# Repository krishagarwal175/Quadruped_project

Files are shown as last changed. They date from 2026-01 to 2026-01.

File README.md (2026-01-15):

# Quadruped Robot Project  
## Consolidated Technical & Progress Report

**Author:** Krish Agarwal  
**Project Duration:** June 2025 – January 2026  
**Status:** Active Development  
**Repository Purpose:** Complete technical, mechanical, electrical, and control-system documentation of the quadruped robot project.

---

## 1. Project Overview

This project documents the end-to-end design, development, and iterative refinement of a servo-actuated quadruped robot. Unlike gait-first hobby projects, this work follows a **stability-first, reflex-based control philosophy**, where standing balance, load management, and failure resilience are solved before aggressive locomotion.

The robot serves as:
- A **research testbed** for embedded control and legged stability
- A **hands-on systems engineering project** covering mechanics, electronics, and software
- A **foundation platform** for future ROS 2, perception, and learning-based extensions

---

## 2. Development Timeline Summary

### Phase 0–1: Concept & Pivot (Month 1)
- Initial work on a humanoid robot exposed critical power-to-weight limitations.
- A decisive pivot was made to a quadruped architecture.
- Learned Fusion 360, ROS, and Gazebo.
- Completed torque calculations and finalized a viable BOM.
- Began simulation-driven gait exploration.

**Key Outcome:** A mechanically and electrically feasible quadruped design.

---

### Phase 2: Mechanical Prototyping & Assembly (Month 2)
- All chassis and leg components 3D printed using PETG.
- Full mechanical assembly completed.
- Multiple redesigns to fix servo fitment, joint weakness, and infill-related failures.
- Hardware prototype became physically complete and software-ready.

**Key Outcome:** Fully assembled physical robot.

---

### Phase 3: Electrical & Platform Stabilization (Month 3)
- Introduced regulated high-current power delivery using a buck converter.
- Validated servo power distribution under load.
- Jetson Orin Nano OS corruption occurred during ROS setup → full system re-flash.
- Designed V2 leg parts after a structural failure.
- Established high-level control architecture plan.

**Key Outcome:** Stable electromechanical platform with lessons learned.

---

### Phase 4: Control Integration & Motion Refinement (Month 4)
- Full chassis rebuild to eliminate flex and rocking.
- Implemented smoother gait trajectories and reduced snap.
- Increased gait speed by ~1.3× after validation.
- Added balancing routines and removed brittle abort logic.
- Implemented configuration export and logging.
- Identified servo feedback and RL training as current hard limits.

**Key Outcome:** Stable, controllable robot with repeatable motion.

---

### Phase 5: Stability-First Control Architecture (Recent Month – Not in Prior Reports)
- Implemented **layered control architecture**:
  - Hardware abstraction
  - PD-based roll/pitch stabilization
  - Reflex behaviors and FSM-based limb control
- Developed brace reflexes and leg unloading detection.
- Enabled safe single-leg lift without collapse.
- Built real-time telemetry and manual override GUIs.
- Achieved controlled crawl-like motion under FSM supervision.

**Key Outcome:** Research-grade reflex-stabilized quadruped.

---

## 3. Mechanical System

- 3 DOF per leg (shoulder, mid-limb, foot)
- PETG 3D-printed chassis with iterative reinforcement
- Structural redesigns driven by real load failures
- Explicit mechanical limits encoded in software

**Lesson:** Mechanical stiffness directly governs control quality.

---

## 4. Electrical & Power Architecture

- 4S 6200 mAh LiPo battery
- Dedicated high-current buck converter for servos
- PCA9685 PWM driver for deterministic pulse generation
- Careful grounding and wiring to avoid I2C instability
- MPU6050 IMU for orientation feedback

**Lesson:** Power isolation is mandatory for legged robots.

---

## 5. Embedded Compute & Software Stack

- NVIDIA Jetson Orin Nano (Ubuntu + JetPack)
- Python-based control stack
- Clean separation of sensing, actuation, and control
- FSM-based behavior sequencing
- Extensive logging and visualization

A Jetson OS corruption event forced a full rebuild, resulting in a **much cleaner and more robust architecture**.

---

## 6. Control Philosophy

### Stability-First Design
- Standing solved before walking
- Reflexes before planning
- Hardware constraints drive software decisions

### Layered Control
- **Layer 0:** Servo mapping, limits, safe init
- **Layer 1:** PD roll/pitch stabilization
- **Layer 2:** Reflexes, unloading checks, FSM behaviors

### Reflex Behaviors
- Brace reflex under disturbances
- Conservative leg unloading checks
- Safe limb lift and replant phases

---

## 7. Current Capabilities

- Stable standing under external pushes
- Reflexive disturbance rejection
- Safe single-leg lift
- Controlled crawl-like motion
- Live telemetry and manual override support

---

## 8. Constraints & Known Limitations

- No joint feedback → positional drift under load
- RL gait training blocked by lack of GPU compute
- Servo thermal and current limits
- Rear-right leg slip at higher speeds
- Manual tuning slows iteration

---

## 9. Engineering Lessons

- Mechanical reality overrides theory
- Failures accelerate architectural maturity
- Visualization is not optional
- Stability-first control simplifies everything downstream

---

## 10. Future Work

- Closed-loop actuation (encoders / smart servos)
- Foot contact sensing
- ROS 2 migration
- Quantitative performance metrics
- Learning-assisted gait optimization (long-term)

---

## 11. Conclusion

This project demonstrates that **meaningful quadruped intelligence can emerge from disciplined control design without complex planners or learning**, provided stability and reflexes are prioritized early.

The robot is now a robust platform for advanced research, experimentation, and future expansion.

---

*End of Consolidated Report*

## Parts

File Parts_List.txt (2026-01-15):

# Quadruped Robot Project – Parts List (BOM)
# Repository-ready text file
# Maintained by: Krish
# Last updated: 2026-01-15

====================================================
1. COMPUTE & CONTROL
====================================================
- NVIDIA Jetson Orin Nano
  Role: High-level control, perception, future autonomy
  OS: Ubuntu (JetPack)

- ESP32 Development Board
  Role: Low-level servo control, gait timing, real-time tasks
  Interface: UART / I2C with Jetson

- PCA9685 16-Channel PWM Servo Driver
  Role: Generates stable PWM signals for servos
  Interface: I2C
  Voltage: 5–6 V logic-compatible

====================================================
2. ACTUATION
====================================================
- DS3240MG High Torque Servo Motors (270°)
  Quantity: 12 (3 per leg × 4 legs)
  Positions:
    - Shoulder (Hip)
    - Mid-limb (Thigh/Knee equivalent)
    - Foot (Ankle)
  Notes:
    - No position feedback
    - Metal gears
    - High stall torque suitable for load-bearing

====================================================
3. POWER SYSTEM
====================================================
- 4S LiPo Battery – 6200 mAh
  Nominal Voltage: 14.8 V
  Fully Charged: 16.8 V
  Role: Main power source

- DC Buck Converter (15–20 V → 5 V)
  Role: Step-down voltage for servos and logic
  Features:
    - Current protection
    - High current capability

- Power Distribution Wiring
  Wire Gauges Used:
    - 10 AWG (main battery lines)
    - 12 AWG (high-current servo rails)
    - 18–22 AWG (logic and signal)

- XT60 / XT90 Connectors
  Role: Battery connection and power safety

====================================================
4. SENSORS
====================================================
- MPU6050 IMU
  Sensors:
    - 3-axis Accelerometer
    - 3-axis Gyroscope
  Role:
    - Orientation estimation
    - Stability feedback
    - PD control reference

====================================================
5. MECHANICAL STRUCTURE
====================================================
- 3D Printed Parts (Material: PETG)
  Components:
    - Main torso frame
    - Shoulder brackets
    - Mid-limb links
    - Foot links
    - Servo mounts
    - Cable routing guides

- Fasteners
  Types:
    - M2 screws and nuts
    - M3 screws and nuts
  Usage:
    - Servo mounting
    - Structural joints

- Bearings / Bushings (where applicable)
  Role: Reduce friction at rotating joints

====================================================
6. FEET & GROUND INTERFACE
====================================================
- Rubber Feet / Pads
  Role:
    - Shock absorption
    - Improved grip
    - Noise reduction

- Optional TPU foot caps
  Role:
    - Compliance
    - Vibration damping

====================================================
7. COMMUNICATION & INTERFACES
====================================================
- I2C Wiring
  Used for:
    - PCA9685
    - MPU6050

- UART Wiring
  Used for:
    - Jetson ↔ ESP32 communication

- USB Cables
  Role:
    - Programming
    - Debugging

====================================================
8. TOOLS & SUPPORTING HARDWARE
====================================================
- Soldering Iron & Solder Wire
- Heat Shrink Tubes
- Multimeter
- Zip Ties / Cable Sleeves
- Thread Locker (medium strength)

====================================================
9. SOFTWARE STACK (REFERENCE)
====================================================
- Ubuntu (Jetson)
- Python
- NumPy
- Matplotlib (visualization & kinematics)
- Custom PD Controllers
- FSM-based gait & limb control
- I2C & GPIO libraries

====================================================
10. NOTES
====================================================
- Architecture is stability-first and reflex-based
- Designed for incremental upgrades:
  - Encoders
  - Force sensors
  - Vision modules
  - ROS 2 integration

End of File

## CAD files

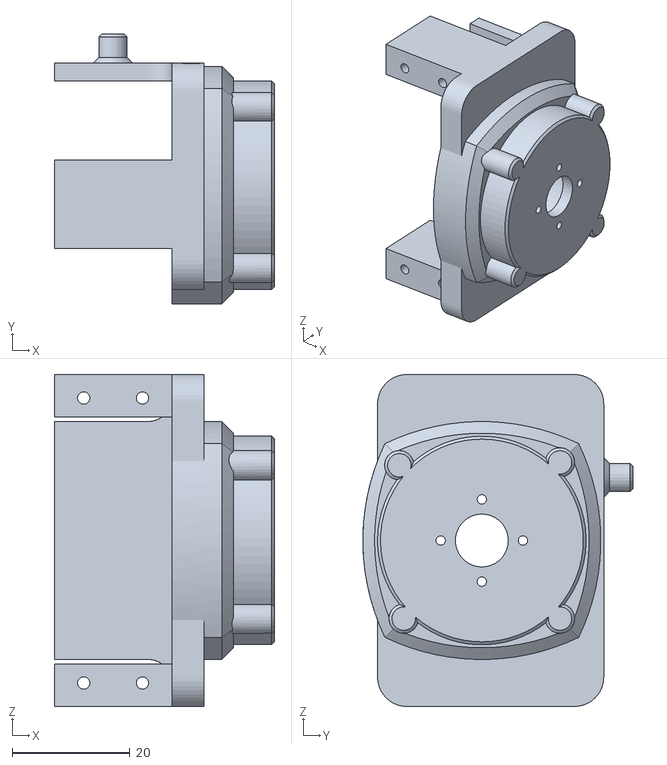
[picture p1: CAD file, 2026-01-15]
Hardware/LeftCoxa.stl
37.5 x 46.0 x 56.5

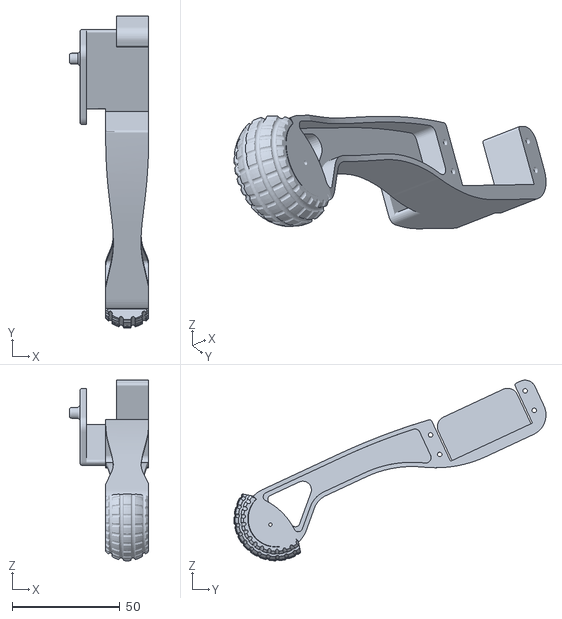
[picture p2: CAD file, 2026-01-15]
Hardware/RightWrist.stl
36.9 x 145.0 x 84.0

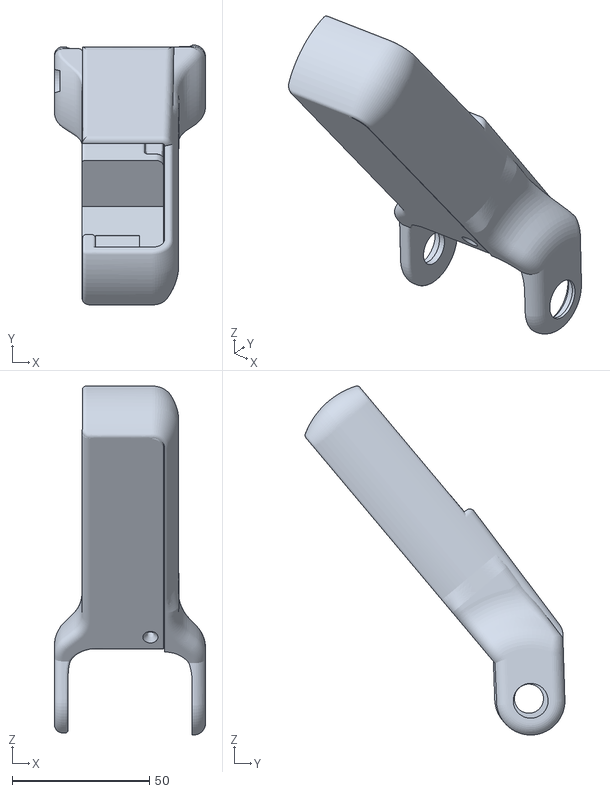
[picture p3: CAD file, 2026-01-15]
Hardware/LeftThigh.stl
55.1 x 94.8 x 127.2

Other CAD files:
Hardware/RightThigh.stl
Hardware/LeftWrist.stl
Hardware/RightCoxa.stl

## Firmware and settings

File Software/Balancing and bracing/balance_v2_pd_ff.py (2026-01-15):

import time, math, errno
from smbus2 import SMBus
import threading 
import tkinter as tk
# ==================================================
# I2C CONFIG (HARDWARE — DO NOT TWEAK)
# ==================================================
BUS = 7
MPU_ADDR = 0x68
PCA_ADDR = 0x40

PWR_MGMT_1 = 0x6B
ACCEL_XOUT_H = 0x3B
GYRO_XOUT_H  = 0x43

MODE1 = 0x00
PRESCALE = 0xFE

CONFIG = 0x1A
GYRO_CONFIG = 0x1B
ACCEL_CONFIG = 0x1C

# ==================================================
# SERVO CONFIG (MECHANICAL LIMITS)
# ==================================================
# PWM pulse range for your servos
# ❌ Do not change unless servo specs change
PULSE_MIN = 80
PULSE_MAX = 561

# ==================================================
# SHOULDER JOINTS — ROLL CONTROL
# ==================================================
# These joints control LEFT–RIGHT balance
# Real-world effect: widening/narrowing stance

SHOULDERS = {
    "FR": 6,
    "FL": 7,
    "RR": 0,
    "RL": 1,
}

SHOULDER_MAX_OFFSET = {
    "FR": 25.0,
    "FL": 25.0,
    "RR": 25.0,
    "RL": 25.0,
}

# Neutral standing angles (MEASURED, DO NOT GUESS)
SHOULDER_STAND = {
    "FR": 41,
    "FL": 41,
    "RR": 38,
    "RL": 38,
}

# Direction mapping:
# +angle → abduct (move outward)
# -angle → adduct (move inward)
# ❌ DO NOT CHANGE unless servo direction is rewired
SHOULDER_SIGN = {
    "FR": +1,
    "RR": +1,
    "FL": -1,
    "RL": -1,
}

# Roll compensation sign:
# Determines which side pushes during roll
# This mapping is CRITICAL for correct roll response
SHOULDER_ROLL_SIGN = {
    "FR": -1,
    "RR": -1,   # right side resists positive roll
    "FL": +1,
    "RL": +1,   # left side supports positive roll
}

# ==================================================
# FOOT (KNEE) JOINTS — PITCH CONTROL
# ==================================================
# These joints control FRONT–BACK balance
# Real-world effect: shifting vertical load

FEET = {
    "FRF": 10,
    "FLF": 11,
    "RRF": 4,
    "RLF": 5,
}

# Neutral standing angles (MEASURED)
FOOT_STAND = {
    "FRF": 128,
    "FLF": 61,
    "RRF": 142,
    "RLF": 61,
}

# Direction mapping:
# +offset → extension or flexion depending on side
# ❌ Change ONLY if mechanical linkage changes
FOOT_SIGN = {
    "FRF": +1,
    "FLF": -1,
    "RRF": +1,
    "RLF": -1,
}

# Mechanical safety limits — PREVENT DAMAGE
FOOT_LIMITS = {k: (0, 190) for k in FEET}

# ==================================================
# CONTROL PARAMETERS (THIS IS WHERE YOU TUNE)
# ==================================================
DT = 0.05        # Control loop timestep (20 Hz)
ALPHA = 0.96     # Complementary filter weight
                 # ↑ Higher = smoother, slower
                 # ↓ Lower = faster, noisier

# ---------- ROLL CONTROL ----------
K_ROLL = 0.8            # Roll stiffness (SAFE TO TWEAK)
MAX_ROLL = 30.0         # IMU roll clamp (SAFETY)
ROLL_STEP = 1.5         # Shoulder speed (deg per cycle)
ROLL_LIMIT = 20.0       # Max shoulder offset (SAFE TO TWEAK)
K_ROLL_RATE = 0.025     # Roll-rate feedforward (gyro-based)

# ---------- PITCH CONTROL ----------
K_PITCH = 0.8        # Pitch stiffness (SAFE TO TWEAK)
MAX_PITCH = 30.0     # IMU pitch clamp (SAFETY)
PITCH_STEP = 1.5     # Knee speed (deg per cycle)
PITCH_LIMIT = 25.0   # Max knee offset (SAFETY)
K_PITCH_RATE = 0.03  # Pitch-rate feedforward(start conservative)

# IMU noise rejection
ACCEL_DEADBAND = 50
GYRO_DEADBAND = 10
GYRO_RATE_DEADBAND = 1.5 

bus = SMBus(BUS)

# ==================================================
# BALANCE EFFORT MONITOR (for unloading detection)
# ==================================================
last_roll_cmd = 0.0
last_roll_offsets = {k: 0.0 for k in SHOULDERS}
roll_effort = 0.0

# ==================================================
# PRINT INTERVAL
# ==================================================
DEBUG_PRINT = False
PRINT_INTERVAL = 2.0 # seconds
last_print = time.time()

# ==================================================
# LOW-LEVEL HARDWARE FUNCTIONS (DO NOT TWEAK)
# ==================================================
def safe_read_word(addr, reg):
    """
    Reads signed 16-bit value from I2C
    Includes protection against transient I2C errors
    """
    try:
        h = bus.read_byte_data(addr, reg)
        l = bus.read_byte_data(addr, reg + 1)
        v = (h << 8) | l
        return v - 65536 if v > 32767 else v
    except OSError as e:
        if e.errno == errno.EREMOTEIO:
            raise IOError
        raise

def angle_to_pulse(angle):
    """
    Converts angle (0–270°) to PCA9685 pulse
    """
    return int(PULSE_MIN + (angle / 270.0) * (PULSE_MAX - PULSE_MIN))

def set_servo_angle(ch, angle):
    """
    Sends final angle command to servo channel
    """
    pulse = angle_to_pulse(angle)
    base = 0x06 + 4 * ch
    bus.write_byte_data(PCA_ADDR, base, 0)
    bus.write_byte_data(PCA_ADDR, base + 1, 0)
    bus.write_byte_data(PCA_ADDR, base + 2, pulse & 0xFF)
    bus.write_byte_data(PCA_ADDR, base + 3, (pulse >> 8) & 0x0F)

# ==================================================
# DEVICE INITIALIZATION (DO NOT TWEAK)
# ==================================================
# Wake IMU
bus.write_byte_data(MPU_ADDR, PWR_MGMT_1, 0x00)
time.sleep(0.1)

# Set MPU6050 Digital Low Pass Flter (~20Hz)
bus.write_byte_data(MPU_ADDR, CONFIG, 0x04)
time.sleep(0.05)

# Initialize PCA9685 at 50 Hz
bus.write_byte_data(PCA_ADDR, MODE1, 0x00)
time.sleep(0.01)
prescale = int(25000000 / (4096 * 50) - 1)
bus.write_byte_data(PCA_ADDR, MODE1, 0x10)
bus.write_byte_data(PCA_ADDR, PRESCALE, prescale)
bus.write_byte_data(PCA_ADDR, MODE1, 0x00)
bus.write_byte_data(PCA_ADDR, MODE1, 0x80)

# ==================================================
# MOVE TO STANDING POSE (SAFE STARTUP)
# ==================================================
# Always bring robot to neutral before control starts
for leg, ch in SHOULDERS.items():
    set_servo_angle(ch, SHOULDER_STAND[leg])
    time.sleep(0.02)

for leg, ch in FEET.items():
    set_servo_angle(ch, FOOT_STAND[leg])
    time.sleep(0.02)

# ==================================================
# IMU CALIBRATION (KEEP ROBOT STILL)
# ==================================================
ax_o = ay_o = az_o = gx_o = gy_o = 0
for _ in range(200):
    ax_o += safe_read_word(MPU_ADDR, ACCEL_XOUT_H)
    ay_o += safe_read_word(MPU_ADDR, ACCEL_XOUT_H + 2)
    az_o += safe_read_word(MPU_ADDR, ACCEL_XOUT_H + 4) - 16384
    gx_o += safe_read_word(MPU_ADDR, GYRO_XOUT_H)
    gy_o += safe_read_word(MPU_ADDR, GYRO_XOUT_H + 2)
    time.sleep(0.01)

ax_o /= 200; ay_o /= 200; az_o /= 200
gx_o /= 200; gy_o /= 200

# ==================================================
# CONTROL STATE VARIABLES
# ==================================================
roll = 0.0
pitch = 0.0

# ADD — BALANCE EFFORT MONITOR (one-time initialization)
# Place immediately after roll/pitch / posture variables
last_roll_cmd = 0.0
last_roll_offsets = {k: 0.0 for k in SHOULDERS}  # store last shoulder offsets
roll_effort = 0.0
offset_change = 0.0

# These store smooth joint offsets
roll_offsets = {k: 0.0 for k in SHOULDERS}
pitch_offsets = {k: 0.0 for k in FEET}

print("Layer-1 Roll + Pitch ACTIVE (±30°)\n")

# ===============================
# LAYER-2: POSTURE / MOTION STATE
# ===============================
# Posture biases (targets + current)
posture_roll_target  = 0.0
posture_pitch_target = 0.0
posture_roll_bias   = 0.0   # current applied bias (will ramp to target)
posture_pitch_bias  = 0.0

POSTURE_MAX_ROLL   = 8.0    # deg - max intentional lean
POSTURE_MAX_PITCH  = 6.0
POSTURE_STEP       = 0.3    # deg per loop - smoothness

# Motion offsets per-joint (added on top of balance offsets)
motion_offsets = {k: 0.0 for k in SHOULDERS}
motion_offsets.update({k: 0.0 for k in FEET})

# Simple ramp helper
def ramp(current, target, step):
    d = target - current
    if d > step: d = step
    if d < -step: d = -step
    return current + d

# Unload posture map (lean away from leg)
UNLOAD_POSTURE = {
    "FRF": {"roll": +POSTURE_MAX_ROLL, "pitch": -POSTURE_MAX_PITCH},
    "FLF": {"roll": -POSTURE_MAX_ROLL, "pitch": -POSTURE_MAX_PITCH},
    "RRF": {"roll": +POSTURE_MAX_ROLL, "pitch": +POSTURE_MAX_PITCH},
    "RLF": {"roll": -POSTURE_MAX_ROLL, "pitch": +POSTURE_MAX_PITCH},
}

# FSM for simple unload + lift of a single leg (start disabled)
swing_leg = None        # e.g. "FRF" when commanded
fsm_state = "IDLE"      # IDLE / UNLOADING / LIFTING / DONE



# LIFT parameters
LIFT_HEIGHT = 12.0      # deg (knee flex offset as motion)
LIFT_STEP = 0.8         # deg per cycle for knee motion
UNLOAD_SETTLE_THRESH = 1.0  # deg — how close IMU must be to posture bias

# ==================================================
# BRACE STATE (NEW)
# ==================================================
BRACE_ACCEL_THRESHOLD = 3000     # raw accel delta
BRACE_DURATION = 0.25            # seconds
BRACE_GAIN_SCALE = 0.6           # soften controller
BRACE_MAX_BIAS = 12.0            # deg (keep small)

brace_active = False
brace_until = 0.0

brace_roll_bias = 0.0
brace_pitch_bias = 0.0

last_ax = last_ay = last_az = 0.0

# ==================================================
# MONITOR STATE (READ-ONLY)
# ==================================================
monitor_state = {
    "roll": 0.0,
    "pitch": 0.0,

    "brace": False,
    "brace_roll_bias": 0.0,
    "brace_pitch_bias": 0.0,

    # Raw acceleration
    "ax": 0.0,
    "ay": 0.0,
    "az": 0.0,
    
    # ADD — debug / unload detection
    "roll_effort": 0.0,
    "offset_change": 0.0,
    "unloaded": False,
}


# store last commanded servo angles
servo_angles = {}

for leg, ch in SHOULDERS.items():
    servo_angles[ch] = SHOULDER_STAND[leg]

for leg, ch in FEET.items():
    servo_angles[ch] = FOOT_STAND[leg]

# ==================================================
# READ-ONLY MONITOR GUI
# ==================================================
def start_monitor_gui():
    root = tk.Tk()
    root.title("Quadruped Layer-1 Monitor")

    # IMU labels
    imu_frame = tk.LabelFrame(root, text="IMU")
    imu_frame.pack(padx=10, pady=5, fill="x")
    # Acceleration labels (raw)
    accel_frame = tk.LabelFrame(root, text="Acceleration (raw)")
    accel_frame.pack(padx=10, pady=5, fill="x")

    ax_var = tk.StringVar()
    ay_var = tk.StringVar()
    az_var = tk.StringVar()
    
    # ADD — new GUI vars for unload debug
    roll_effort_var = tk.StringVar()
    offset_change_var = tk.StringVar()
    unloaded_var = tk.StringVar()
    
    roll_var = tk.StringVar()
    pitch_var = tk.StringVar()
    brace_var = tk.StringVar()
    brace_roll_var = tk.StringVar()
    brace_pitch_var = tk.StringVar()
    tk.Label(imu_frame, textvariable=roll_var, font=("Arial", 12)).pack(anchor="w")
    tk.Label(imu_frame, textvariable=pitch_var, font=("Arial", 12)).pack(anchor="w")
    tk.Label(imu_frame, textvariable=brace_var, font=("Arial", 12)).pack(anchor="w")
    tk.Label(imu_frame, textvariable=brace_roll_var, font=("Arial", 12)).pack(anchor="w")
    tk.Label(imu_frame, textvariable=brace_pitch_var, font=("Arial", 12)).pack(anchor="w")
    tk.Label(accel_frame, textvariable=ax_var, font=("Arial", 10)).pack(anchor="w")
    tk.Label(accel_frame, textvariable=ay_var, font=("Arial", 10)).pack(anchor="w")
    tk.Label(accel_frame, textvariable=az_var, font=("Arial", 10)).pack(anchor="w")
    
    # Place them under the accel_frame (or imu_frame) so they're visible
    tk.Label(imu_frame, textvariable=roll_effort_var, font=("Arial", 10)).pack(anchor="w")
    tk.Label(imu_frame, textvariable=offset_change_var, font=("Arial", 10)).pack(anchor="w")
    tk.Label(imu_frame, textvariable=unloaded_var, font=("Arial", 10)).pack(anchor="w")

    # Servo labels
    servo_frame = tk.LabelFrame(root, text="Servo Angles (deg)")
    servo_frame.pack(padx=10, pady=5)

    servo_vars = {}

    for ch in sorted(servo_angles.keys()):
        var = tk.StringVar()
        servo_vars[ch] = var
        tk.Label(
            servo_frame,
            textvariable=var,
            font=("Arial", 10),
            width=22,
            anchor="w"
        ).pack(anchor="w")

    def update():
        roll_var.set(f"Roll  : {monitor_state['roll']:+6.2f}°")
        pitch_var.set(f"Pitch : {monitor_state['pitch']:+6.2f}°")
        brace_var.set("Brace : ACTIVE" if monitor_state["brace"] else "Brace : off")
        brace_roll_var.set(f"Brace Roll Bias  : {monitor_state['brace_roll_bias']:+6.2f}°")
        brace_pitch_var.set(f"Brace Pitch Bias : {monitor_state['brace_pitch_bias']:+6.2f}°")
        
        # ADD — update debug vars from shared monitor_state
        roll_effort_var.set(f"Roll Effort   : {monitor_state.get('roll_effort', 0.0):.3f}")
        offset_change_var.set(f"Offset Change : {monitor_state.get('offset_change', 0.0):.3f}")
        unloaded_var.set(f"UNLOADED      : {monitor_state.get('unloaded', False)}")
        
        ax_var.set(f"AX : {monitor_state['ax']:6.0f}")
        ay_var.set(f"AY : {monitor_state['ay']:6.0f}")
        az_var.set(f"AZ : {monitor_state['az']:6.0f}")

        for ch, var in servo_vars.items():
            var.set(f"CH {ch:2d} → {servo_angles[ch]:6.2f}°")

        root.after(100, update)  # 10 Hz GUI refresh

    update()
    root.mainloop()
    
threading.Thread(
    target=start_monitor_gui,
    daemon=True
).start()    
# ==================================================
# MAIN CONTROL LOOP — LAYER 1 REFLEX
# ==================================================
while True:
    try:
        # Read IMU
        ax = safe_read_word(MPU_ADDR, ACCEL_XOUT_H) - ax_o
        ay = safe_read_word(MPU_ADDR, ACCEL_XOUT_H + 2) - ay_o
        az = safe_read_word(MPU_ADDR, ACCEL_XOUT_H + 4) - az_o
        gx = safe_read_word(MPU_ADDR, GYRO_XOUT_H) - gx_o
        gy = safe_read_word(MPU_ADDR, GYRO_XOUT_H + 2) - gy_o
        
        # ---------- BRACE DETECTION ----------
        dax = ax - last_ax
        day = ay - last_ay
        daz = az - last_az
        last_ax, last_ay, last_az = ax, ay, az

        delta_a = math.sqrt(dax*dax + day*day + daz*daz)

        now = time.time()

        if (delta_a > BRACE_ACCEL_THRESHOLD) and not brace_active:
            brace_active = True
            brace_until = now + BRACE_DURATION

            mag = max(delta_a, 1.0)
            brace_pitch_bias = -dax / mag * BRACE_MAX_BIAS
            brace_roll_bias  = -day / mag * BRACE_MAX_BIAS
            
            # ---------- BRACE DECAY ----------
        if brace_active:
            if now > brace_until:
                brace_active = False
                brace_roll_bias = 0.0
                brace_pitch_bias = 0.0
            else:
                # gentle decay inside brace window
                brace_roll_bias *= 0.92
                brace_pitch_bias *= 0.92

        # Noise suppression
        if abs(ax) < ACCEL_DEADBAND: ax = 0
        if abs(ay) < ACCEL_DEADBAND: ay = 0
        if abs(gx) < GYRO_DEADBAND: gx = 0
        if abs(gy) < GYRO_DEADBAND: gy = 0

        # IMU tilt estimation
        accel_roll  = math.degrees(math.atan2(ay, az))
        accel_pitch = math.degrees(math.atan2(-ax, math.sqrt(ay*ay + az*az)))

        # Complementary filter (gyro + accel)
        roll  = ALPHA * (roll  + gx / 131.0 * DT) + (1 - ALPHA) * accel_roll
        pitch = ALPHA * (pitch + gy / 131.0 * DT) + (1 - ALPHA) * accel_pitch

        roll  = max(-MAX_ROLL,  min(MAX_ROLL,  roll))
        pitch = max(-MAX_PITCH, min(MAX_PITCH, pitch))
        
        monitor_state["roll"] = roll
        monitor_state["pitch"] = pitch
        
        # ==================================================
        # APPLY POSTURE BIAS (Layer-2)
        # ==================================================

        # Ramp posture bias toward target
        posture_roll_bias  = ramp(posture_roll_bias,  posture_roll_target,  POSTURE_STEP)
        posture_pitch_bias = ramp(posture_pitch_bias, posture_pitch_target, POSTURE_STEP)

        # Effective tilt relative to desired posture
        effective_roll  = roll  - posture_roll_bias
        effective_pitch = pitch - posture_pitch_bias

        # Monitor
        monitor_state["posture_roll_bias"]  = posture_roll_bias
        monitor_state["posture_pitch_bias"] = posture_pitch_bias
        monitor_state["brace"] = brace_active
        monitor_state["brace_roll_bias"] = brace_roll_bias
        monitor_state["brace_pitch_bias"] = brace_pitch_bias
        monitor_state["ax"] = ax
        monitor_state["ay"] = ay
        monitor_state["az"] = az

        if DEBUG_PRINT and (time.time() - last_print) > PRINT_INTERVAL:
            print(f"Roll:{roll:6.2f}°  Pitch:{pitch:6.2f}°")
            last_print = time.time()


        # ==================================================
        # LAYER-2 FSM: UNLOAD → LIFT
        # ==================================================

        if fsm_state == "IDLE":
            if swing_leg is not None:
                posture_roll_target  = UNLOAD_POSTURE[swing_leg]["roll"]
                posture_pitch_target = UNLOAD_POSTURE[swing_leg]["pitch"]
                unload_start = time.time()
                fsm_state = "UNLOADING"

        elif fsm_state == "UNLOADING":
            # REPLACE — improved unloading detection (uses controller effort + offset change)
            # UNLOADED when:
            #  - IMU near posture bias (small angular error)
            #  - roll controller effort is low (controller relaxed)
            #  - shoulder offset changes are small (no more balancing adjustments)
            UNLOADED = (
                abs(roll  - posture_roll_bias)  < UNLOAD_SETTLE_THRESH and
                abs(pitch - posture_pitch_bias) < UNLOAD_SETTLE_THRESH and
                roll_effort < 0.15 and                # controller slow to change (tunable)
                offset_change < 0.05                  # shoulder offsets nearly steady (tunable)
            )

            # ADD — publish unload boolean for GUI
            monitor_state["unloaded"] = bool(UNLOADED)

            if UNLOADED and (time.time() - unload_start) > 0.5:
                # confirmed unload — proceed to lift
                fsm_state = "LIFTING"

        elif fsm_state == "LIFTING":
            current = motion_offsets[swing_leg]
            motion_offsets[swing_leg] = ramp(current, LIFT_HEIGHT, LIFT_STEP)

            if abs(motion_offsets[swing_leg] - LIFT_HEIGHT) < 0.5:
                fsm_state = "DONE"

        elif fsm_state == "DONE":
            pass  # hold for now

        # ---------- ROLL REFLEX ----------
        # Shoulders widen/narrow stance to resist tipping
        gain_scale = BRACE_GAIN_SCALE if brace_active else 1.0
        roll_rate = gx / 131.0      #deg/s
        if abs(roll_rate) < GYRO_RATE_DEADBAND:
            roll_rate = 0.0
        # USE effective_roll instead of raw roll
        roll_cmd = -(gain_scale * (K_ROLL * effective_roll + K_ROLL_RATE * roll_rate)) + brace_roll_bias
        
        roll_cmd = max(-ROLL_LIMIT, min(ROLL_LIMIT, roll_cmd))
        
        # ADD — measure change in roll command (effort)
        # Place right after roll_cmd is computed
        roll_effort = abs(roll_cmd - last_roll_cmd)
        last_roll_cmd = roll_cmd
        
        # ADD — publish to monitor_state for GUI
        monitor_state["roll_effort"] = roll_effort
        
        

        for leg, ch in SHOULDERS.items():
            delta = roll_cmd - roll_offsets[leg]
            delta = max(-ROLL_STEP, min(ROLL_STEP, delta))
            if abs(delta) < 0.05:
                delta = 0.0
            roll_offsets[leg] += delta

            roll_offsets[leg] = max(
                -SHOULDER_MAX_OFFSET[leg],
                min(SHOULDER_MAX_OFFSET[leg], roll_offsets[leg])
            )   

            # Final shoulder angle = stand + balance + motion
            angle = (
                SHOULDER_STAND[leg]
                + roll_offsets[leg]         # Layer-1 balance
                + motion_offsets[leg]       # Layer-2 motion
            )

            set_servo_angle(ch, angle)
            servo_angles[ch] = angle
            
        # ADD — compute average shoulder offset change (how much roll offsets moved this loop)
        # Place right after the shoulder loop ends
        offset_sum = 0.0
        for leg in SHOULDERS:
            offset_sum += abs(roll_offsets[leg] - last_roll_offsets[leg])
            last_roll_offsets[leg] = roll_offsets[leg]
        offset_change = offset_sum / max(1, len(SHOULDERS))    

        # ADD — publish to monitor_state for GUI
        monitor_state["offset_change"] = offset_change
        


        # ---------- PITCH REFLEX ----------
        # Knees flex/extend to shift vertical load
        for leg, ch in FEET.items():
            
            pitch_rate = gy / 131.0     # deg/s
            if abs(pitch_rate) < GYRO_RATE_DEADBAND:
                pitch_rate = 0.0
            # USE effective_pitch instead of raw pitch
            tgt = (gain_scale * (K_PITCH * effective_pitch + K_PITCH_RATE * pitch_rate) + brace_pitch_bias) * (1 if leg.startswith("F") else -1)
            tgt = max(-PITCH_LIMIT, min(PITCH_LIMIT, tgt))

            delta = tgt - pitch_offsets[leg]
            delta = max(-PITCH_STEP, min(PITCH_STEP, delta))
            if abs(delta) < 0.05:
                delta = 0.0
            pitch_offsets[leg] += delta

            # Final foot angle = stand + balance + motion
            angle = (
                FOOT_STAND[leg]
                + FOOT_SIGN[leg] * pitch_offsets[leg]   # Layer-1 balance
                + motion_offsets[leg]                   # Layer-2 motion
            )

            angle = max(FOOT_LIMITS[leg][0], min(FOOT_LIMITS[leg][1], angle))
            set_servo_angle(ch, angle)
            servo_angles[ch] = angle

        time.sleep(DT)

    except IOError:
        print("I2C glitch — holding posture")
        time.sleep(0.2)

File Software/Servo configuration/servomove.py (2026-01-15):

# ============================================================
# Servo GUI Test – Jetson Orin Nano + PCA9685
# Fresh start, single file
# ============================================================

import sys
import time
import tkinter as tk
from tkinter import messagebox

# ----------------------------
# I2C / PCA9685 imports
# ----------------------------
try:
    from smbus2 import SMBus
    from adafruit_pca9685 import PCA9685
except Exception as e:
    print("ERROR: Failed to import PCA9685 libraries")
    print(e)
    sys.exit(1)

# ============================================================
# CONFIGURATION SECTION
# ============================================================

PCA9685_I2C_ADDRESS = 0x40
SERVO_FREQUENCY = 50  # Hz

# Safe pulse limits (in microseconds)
SERVO_MIN_US = 500
SERVO_MAX_US = 2500

# ----------------------------
# Servo channel mapping
# Edit these according to YOUR robot
# ----------------------------
SERVO_MAP = {
    "Front Left Hip": 0,
    "Front Left Knee": 1,
    "Front Right Hip": 2,
    "Front Right Knee": 3,
    "Rear Left Hip": 4,
    "Rear Left Knee": 5,
    "Rear Right Hip": 6,
    "Rear Right Knee": 7,
}

# ----------------------------
# Standing / neutral positions
# (degrees)
# ----------------------------
STANDING_ANGLES = {
    "Front Left Hip": 90,
    "Front Left Knee": 90,
    "Front Right Hip": 90,
    "Front Right Knee": 90,
    "Rear Left Hip": 90,
    "Rear Left Knee": 90,
    "Rear Right Hip": 90,
    "Rear Right Knee": 90,
}

# ============================================================
# LOW-LEVEL SERVO DRIVER
# ============================================================

class ServoController:
    def __init__(self):
        try:
            self.bus = SMBus(1)   # Jetson I2C-1
            self.pca = PCA9685(self.bus, address=0x40)
            self.pca.frequency = 50
        except Exception as e:
            print("I2C INIT FAILED")
            print(e)
            sys.exit(1)

    def angle_to_duty(self, angle):
        # Clamp angle
        angle = max(0, min(180, angle))

        pulse_us = SERVO_MIN_US + (angle / 180.0) * (SERVO_MAX_US - SERVO_MIN_US)
        duty = int((pulse_us / 1_000_000) * SERVO_FREQUENCY * 65535)
        return duty

    def set_angle(self, channel, angle):
        try:
            duty = self.angle_to_duty(angle)
            self.pca.channels[channel].duty_cycle = duty
        except Exception as e:
            print(f"ERROR: Failed to move servo on channel {channel}")
            print(e)

    def shutdown(self):
        try:
            self.pca.deinit()
        except:
            pass

# ============================================================
# GUI APPLICATION
# ============================================================

class ServoGUI:
    def __init__(self, root):
        self.root = root
        self.root.title("Quadruped Servo Test – PCA9685")
        self.root.geometry("500x600")

        self.controller = ServoController()
        self.sliders = {}

        title = tk.Label(
            root,
            text="Servo Slider Test (One by One)",
            font=("Arial", 14, "bold")
        )
        title.pack(pady=10)

        for servo_name, channel in SERVO_MAP.items():
            self._create_servo_slider(servo_name, channel)

        reset_btn = tk.Button(
            root,
            text="Move All to Standing Position",
            command=self.move_to_standing,
            bg="#dddddd"
        )
        reset_btn.pack(pady=10)

        exit_btn = tk.Button(
            root,
            text="Exit Safely",
            command=self.safe_exit,
            bg="#ffcccc"
        )
        exit_btn.pack(pady=5)

    # ----------------------------
    # Slider creator
    # ----------------------------
    def _create_servo_slider(self, name, channel):
        frame = tk.Frame(self.root)
        frame.pack(fill="x", padx=10, pady=5)

        label = tk.Label(frame, text=f"{name} (CH {channel})", width=22, anchor="w")
        label.pack(side="left")

        slider = tk.Scale(
            frame,
            from_=0,
            to=180,
            orient="horizontal",
            length=200,
            command=lambda val, ch=channel: self.on_slider_move(ch, val)
        )
        slider.pack(side="right")

        # Set initial standing position
        start_angle = STANDING_ANGLES.get(name, 90)
        slider.set(start_angle)
        self.controller.set_angle(channel, start_angle)

        self.sliders[name] = slider

    # ----------------------------
    # Slider callback
    # ----------------------------
    def on_slider_move(self, channel, value):
        try:
            angle = int(float(value))
            self.controller.set_angle(channel, angle)
        except Exception as e:
            print("ERROR during slider movement")
            print(e)

    # ----------------------------
    # Reset pose
    # ----------------------------
    def move_to_standing(self):
        for name, slider in self.sliders.items():
            angle = STANDING_ANGLES.get(name, 90)
            slider.set(angle)

    # ----------------------------
    # Safe exit
    # ----------------------------
    def safe_exit(self):
        self.controller.shutdown()
        self.root.destroy()

# ============================================================
# MAIN
# ============================================================

if __name__ == "__main__":
    root = tk.Tk()
    app = ServoGUI(root)
    root.protocol("WM_DELETE_WINDOW", app.safe_exit)
    root.mainloop()
